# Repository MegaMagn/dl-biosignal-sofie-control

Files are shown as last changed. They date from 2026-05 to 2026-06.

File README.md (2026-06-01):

# Deep Learning-Based Biosignal Control of a Soft Hand Exoskeleton for Grasp Assistance

Soft, modular hand exoskeleton with integrated sensing and deep learning-based EEG/EMG control for grasp assistance.

## Overview

This repository contains the files used for the development of a soft hand exoskeleton and a deep learning-based biosignal classification framework for real-time grasp assistance.

The project is divided into two main parts:

* **Exoskeleton**
  Contains the mechanical design files, embedded firmware, electronics-related code, and supporting files required to fabricate, assemble, and control the soft hand exoskeleton.

* **Deep Learning-Based Classification**
  Contains the code used for EEG/EMG preprocessing, model training, validation, real-time classification, and biosignal-based control demonstrations.

Together, these components form a soft wearable exoskeleton system capable of assisting pinch grasping through tendon-driven actuation and user-intention decoding.

## Repository structure

```text
.
├── Deep Learning-Based Biosignal Control of a Soft Hand Exoskeleton for Grasp Assistance - report
├── Supplementary - Deep Learning-Based Biosignal Control of a Soft Hand Exoskeleton for Grasp Assistance
│   
├── Exoskeleton
│   ├── Code
│   ├── Enclosure
│   ├── Index and thumb version
│   ├── Index only version
│   └── Miscellaneous
│   
└── Deep Learning-Based Classification
    ├── Code
    │   ├── data_fusion
    │   ├── experiment
    │   ├── models
    │   └── utilities
    │
    └── MuJoCo
```

## Folders and files

### Exoskeleton

#### Code

Contains the embedded and computer-side code used to control, communicate with, and log data from the exoskeleton.

* **Arduino_ESP32 project files**
  Contains the Arduino `.ino`, `.cpp`, and `.h` files for controlling the exoskeleton and logging sensor data on the ESP32.

* **Arduino_ESP32_EMG_control project files**
  Contains the Arduino `.ino`, `.cpp`, and `.h` files for controlling the exoskeleton using commands from the classification network.

* **ESPLogger.py**
  Python script for communication and data logging between the computer and the exoskeleton.

* **requirements.txt**
  Required Python packages for the exoskeleton-side logging and communication scripts.

#### Enclosure

Contains the `.stl` files used for the electronics and actuator enclosure.

#### Index and thumb version

Contains the `.stl` files for constructing the main glove, the thumb module, and the index module. This folder also includes different PTFE tube clamps used to secure the tendon guide tubes to the glove.

#### Index only version

Contains the `.stl` files for constructing the main glove and index finger module. This version was used for early testing and characterization of the integrated sensors.

#### Miscellaneous

Contains miscellaneous files used for test setups, fixtures, and supporting experiments.

### Deep Learning-Based Classification

Contains the code used to develop and evaluate the biosignal classification framework.

This includes scripts for:

* EEG and EMG preprocessing
* Dataset preparation and segmentation
* Subject-dependent and subject-independent model training
* LSTM, CNN+LSTM, and CNN+LSTM+Attention models
* EEG/EMG decision-level fusion
* Hyperparameter optimization
* Real-time inference
* Digital twin visualization
* Biosignal-based exoskeleton control demonstrations

## Hardware needed

The following hardware was used for the exoskeleton system:

* ESP32 30-pin development board
* Pololu Micro Metal Gear Motor, 6 V, 250:1 gear ratio
* Pololu 5 V step-up/step-down buck converter
* SparkFun Micro Magnetometer - MMC5983MA, Qwiic
* 6 mm × 2 mm round neodymium magnet
* Adafruit PCA9546 4-channel STEMMA QT / Qwiic I2C multiplexer
* Pololu DRV8835 dual motor driver
* 7.4 V, 1000 mAh, 2S LiPo battery
* 1 kΩ resistors for the StretchSense voltage divider
* Flexible braided thin steel wire for tendon actuation
* PTFE tubing for tendon guidance
* Assorted resistors, capacitors, and an operational amplifier for current sensing, if desired

## Materials and printing

The exoskeleton is primarily printed in **varioShore TPU** from colorFabb using a Prusa MK3S and a Prusa XL 5T.

Recommended printing settings from colorFabb were used, with a nozzle temperature and layer height of:

```text
220 °C
0.2 mm
```

The StretchSense sensor is printed using **Conductive Filaflex TPU** from Recreus. The filament should be dried before printing and printed using the recommended settings from Recreus. In this project, StretchSense was printed on a Prusa MK3S using a nozzle temperature and layer height of:

```text
240 °C
0.1 mm
```

## Software environment

The Python code was developed using Python 3.11.

Create and activate a virtual environment:

```bash
py -3.11 -m venv .venv
source .venv/Scripts/activate
```

Install the required Python packages:

```bash
pip install -r requirements.txt
```

On Windows PowerShell, the virtual environment can also be activated using:

```powershell
.venv\Scripts\Activate.ps1
```

## Arduino / ESP32 setup

The exoskeleton firmware is intended to run on an ESP32 development board using the Arduino framework.

Before uploading the firmware, make sure that:

* The ESP32 board package is installed in the Arduino IDE.
* The correct ESP32 board and COM port are selected.
* Required libraries for the motor driver, I2C sensors, and communication are installed.
* The wiring matches the pin definitions used in the firmware configuration files.

## Notes

This repository contains research prototype files. The exoskeleton was developed for experimental validation and should be tested carefully before being used with human participants.

When working with the device:

* Check tendon routing before actuation.
* Verify motor direction and software limits.
* Ensure that the exoskeleton can release tension safely.
* Avoid excessive tendon tension.
* Disconnect power when modifying the electronics or mechanical structure.

## Project title

**Deep Learning-Based Biosignal Control of a Soft Hand Exoskeleton for Grasp Assistance**

## Authors

Magnus Malthe Sigsgaard Nielsen  
Nicklas Nikolaj Grønvall

University of Southern Denmark
SDU Biorobotics / SDU Soft Robotics

## License

No license has currently been selected for this repository. All rights reserved.

The contents of this repository are made available for reference and documentation purposes only. Non-commercial use, sharing, distribution, and reproduction in any medium or format are permitted, provided that appropriate credit is given to the original authors and source

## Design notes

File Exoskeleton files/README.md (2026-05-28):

# SoFiE: Soft Finger Exoskeleton for Intelligent Grasping
Soft, wearable, 3D printable, and modular exoskeleton with integrated tactile and proprioceptive sensing.

## Overview
Here, you will find all the necessary files to print and assemble your own soft exoskeleton and control it.

## Folders and files
- Code  
  - Arduino_ESP32 project files  
      Contains the Arduino .ino file and the .cpp and .h files for controlling and logging data on the ESP32.
  - Arduino_ESP32_EMG_control project files  
      Contains the Arduino .ino file and the .cpp and .h files for controlling the exoskeleton with the classification network.
  - ESPLogger.py  
      The logging and communication script meant to run on the computer in conjunction with the exoskeleton.
  - requirements.txt  
      required python packages
- Enclosure  
    Contains the .stl files used for the electronics enclosure.
- Index and thumb version  
    Contains the .stl files for constructing the main glove part, the thumb module and the index module, along with an assortment of PTFE tube clamps used to secure the PTFE tubes to the glove 
- Index only version  
    Contains the .stl files for constructing the main glove part and the index module.
- Miscellaneous  
    Contains some miscellaneous files for some of the test setups
   
## Hardware needed
* ESP32s 30 pin devboard
* Pololu Micro Metal Gear Motor (6V, 250:1)
* Pololu 5V Step up/Step down buck converter
* sparkFun Micro Magnetometer - MMC5983MA (Qwiic)
* 6 mm x 2 mm round Neudymium magnet
* Adafruit PCA9546 4-Channel STEMMA QT / Qwiic I2C Multiplexer
* Pololu DRV8835 Dual Motor driver
* 7.4 V, 1000 mAh, 2S LiPo battery
* 1 k Ohm resistors for StretchSense voltage divider
* flexible braided thin steel wire
* A lenght of PTFE tubing
* Assortment of resistors, capacitors and an opAmp for current sense if wanted.

## Materials and printing
The exoskeleton is primarily printed on a Prusa MK3s and a Prusa XL 5T in red varioShore TPU from Colorfabb. It is printed using their recommended settings, at a nozzle temperature of 220°C  
The StretchSense sensor is made of Conductive Filaflex TPU from Recreus, again dried and printed using their recommended settigns on a Prusa MK3s at a nozzle temeperature of 240°C

## Environment
Python version: 3.11  
Install:  
py -3.11 -m venv .venv  
source .venv/Scripts/activate  
pip install -r requirements.txt

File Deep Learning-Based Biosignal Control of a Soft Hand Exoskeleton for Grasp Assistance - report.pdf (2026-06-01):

# Deep Learning-Based Biosignal Control of a Soft Hand Exoskeleton for Grasp Assistance

Magnus Malthe Sigsgaard Nielsen1

## , Nicklas Nikolaj Grønvall¹

, Xiaofeng Xiong*¹
and Saravana

Prashanth Murali Babu*¹

1SDU Biorbotics, SDU Soft Robotics, University of Southern Denmark, Odense, 5230, Denmark

E-mail: xizi@mmmi.sdu.dk, E-mail: spmb@mmmi.sdu.dk.

*Supervisor.

Keywords: Brain-Computer Interface, Exoskeleton, Real-Time control, Soft Robotics, Deep Neural Network, Flexible Mechanism

### Exam number: Magnus Nielsen: 182180190 ; Nicklas Grønvall: 4110717

Exam project: Master thesis (Robot Systems) (Drones and Autonomous Systems)

## Date of Submission: June 1, 2026

## Word count: ~24400

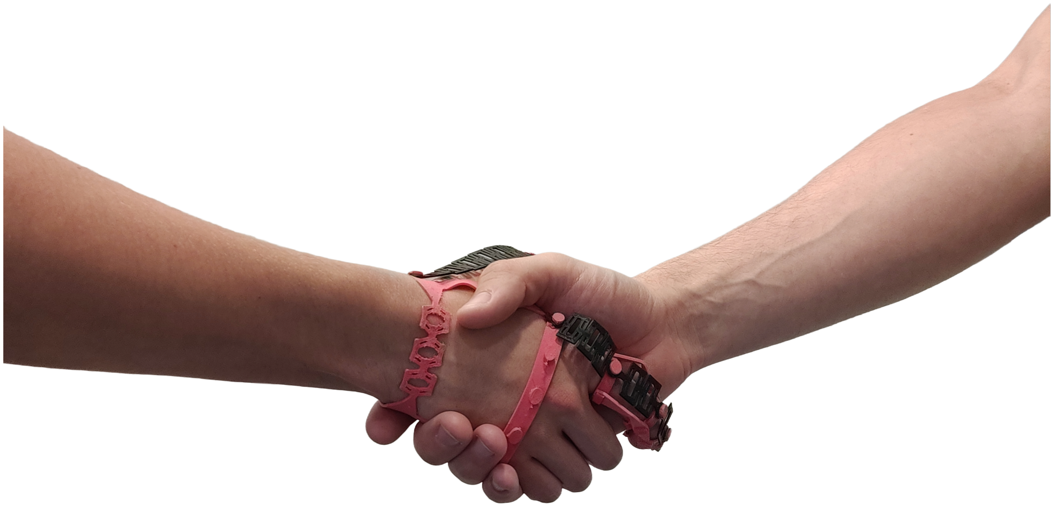
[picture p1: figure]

# Abstract

Hand function and independent dexterity are frequently compromised by age-related decline, trau-

matic injury, and prevalent inflammatory or neurological conditions such as rheumatoid arthritis and

carpal tunnel syndrome. This thesis presents the design, fabrication, and testing of SoFiE (Soft Finger

Exoskeleton for Intelligent Grasping), a lightweight, modular, 3D-printed soft wearable robotic plat-

form customized for pinch-grasp assistance. Fabricated using variable-shore TPU to optimize structural

compliance and user comfort. SoFiE utilizes a single-actuator, underactuated tendon mechanism with

a floating pulley to distribute force between the thumb and index finger. Two embedded sensing modal-

ities provide feedback: StretchSense, a conductive flexible spring providing passive extension forces

and proxy for position tracking, and MagSense, a fingertip magnet-magnetometer pair that measures

contact detection and material compliance. To enable intuitive control, an intention decoding control

pipeline was developed using sequential deep learning architectures, including LSTM, CNN+LSTM,

and CNN+LSTM with attention, evaluated across EEG and EMG signals. System evaluations across

17 participants proved that while decision-level multi-sensor fusion suffers from low EEG signal-to-

noise ratios, an EMG-driven CNN+LSTM network architecture effectively overcomes muscle crosstalk,

achieving an exceptional subject-independent classification accuracy ceiling of 99.4%. Real-time online

validation coupled with a digital twin yielded an optimal response latency of 0.45 ± 0.79 s. Finally,

functional human-in-the-loop grasping evaluations demonstrated that while a passive configuration

introduces minimal baseline resistance, active assistance dynamically attenuates user metabolic demand,

achieving a statistically profound 92.6% reduction in muscular effort during heavy, object-loaded lifting

tasks. These results demonstrate the potential of SoFiE for intuitive, low-effort pinch assistance using

real-time biosignal-driven control.

# Contents

1 Introduction | 3
2 Methods | 7
3 Experimental Methodology | 27
4 Results | 33
5 Discussion | 44
6 Conclusion | 51

# 1. Introduction

The human hand is among the most dexterous structures of the human body, allowing humans to

interact with and adapt to the surrounding environment. Through a combination of fine motor control,

powerful grasping, and rich tactile feedback, the hand can perform a wide range of daily tasks, from

delicate manipulation of small objects to stable handling of larger or heavier objects (Maw et al 2016).

In addition to being mechanically important for grasping and manipulation, the hand is central to tactile

perception and adaptive interaction with the environment (Fischer et al 2014). Despite this versatility,

hand function is vulnerable to impairment caused by neurological disorders, physical injury, repetitive

strain, inflammatory disease, and age-related decline (Gopal et al 2022).

Carpal tunnel syndrome | (CTS) is | a | common | hand impairment associated with repetitive | and

monotonous wrist activities, as well as rheumatoid inflammation. CTS can cause pain, numbness, and

tingling in the hand, especially in the thumb and index finger, and may reduce grip strength and hand

function (Genova et al 2020).

Rheumatoid arthritis (RA), the most common form of inflammatory arthritis, is characterized by

immune-mediated damage to joints, muscles, tendons, and bone structures. This leads to inflammation,

swelling, pain, and in severe cases permanent disability. RA commonly affects small joints, including

those in the hands and feet (Mohammed et al 2020).

CTS, RA, neurological disorders, physical injuries, and age-related weakness can all reduce hand

mobility, grip strength, and the ability to perform activities of daily living. These limitations are espe-

cially problematic when they affect the pinch grasp, since pinch motion is essential for fine and precise

manipulation. Modern grasp taxonomies identify thumb-finger and lateral pinch patterns as important

grasp types used in everyday manipulation tasks (Feix et al 2016; Napier 1956) and the coordination

between the thumb and index finger allows humans to pick up small objects, button clothes, hold a pen,

operate tools, and interact with electronic devices (Duruoz 2014; Kivell 2021).

For people with reduced hand function, loss of pinch strength or pinch coordination can therefore

reduce functional independence and quality of life (Hyun et al 2015).

To address hand impairments like RA, clinical care often combines exercise and rest with assistive

devices to preserve mobility and minimize joint stress Boer et al 2009. This motivates the development

of soft wearable hand exoskeletons capable of assisting grasping and reducing muscular effort. For

effective pinch assistance, such devices must provide sufficient force, coordinated thumb-index motion,

reliable sensing, and compliant, comfortable hand interaction. Assistive hand devices can be passive or

active (Birch et al 2008), depending on whether they support the hand mechanically or provide powered

assistance or resistance. One example of an active assistive device is the I-Phlex finger exoskeleton

(Figure 1A), which demonstrated how active mobilization can increase the range of motion of the

knuckles and thereby reduce joint stiffness (Peperoni et al 2024).

More generally, hand exoskeletons have evolved from rigid linkage-based systems toward softer and

more wearable architectures. Rigid exoskeletons can provide accurate motion guidance and high force

transmission, and they have shown strong potential for rehabilitation and force augmentation (Plessis

et al 2021; Sarac et al 2019). However, they often require careful joint alignment, include bulky

mechanical structures, and may restrict natural hand motion or reduce comfort during prolonged use.

Soft and compliant hand exoskeletons address several of these limitations by using flexible materials,

tendon-driven mechanisms, fabric structures, or fluidic actuators (Figure 1B) that better conform to the

hand and allow more natural movement (Chu and Patterson 2018; Polygerinos et al 2015). Rudd et al.

proposed a sub $200 3D-printed soft hand exoskeleton (Figure 1C) for use in hand therapy, providing

a simpler, cheaper, and more flexible alternative to many commercially available products (Rudd

et al 2019). A review by Heo et al. compares different types of hand exoskeleton technologies for

rehabilitation and assistance. Although more than a decade has passed since the publication of the

review, many of the principles and mechanisms are still used in current designs (Heo et al 2012). The

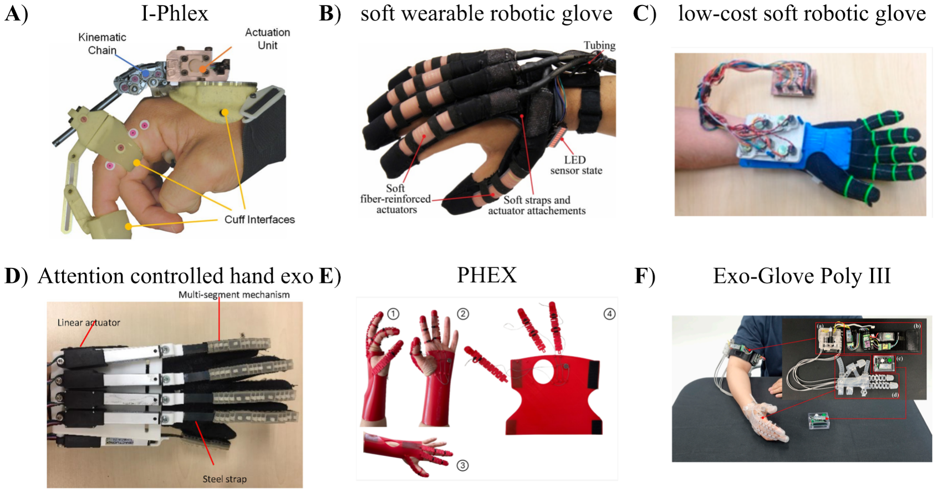
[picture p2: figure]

Figure 1. six examples of wearable robotic gloves. A I-Phlex designed by Peperoni et al. utilizing rigid links to transmit actuation force. B a soft wearable robotic glove designed by Polygerinos et al. using molded elastomeric chambers with fluid pressurization for actuation. C a low-cost soft robotic glove design by Rudd et al. utilizing 3D printing to minimize cost and tendons for actuation. D an attention controlled hybrid rigid-soft hand exoskeleton designed by Li et al. using EEG as a brain-controlled switch to actuate the exoskeleton. E PHEX, a pediatric hand exoskeleton for activities of daily living designed by D’Angelo et al. using a passive cable and spring setup for assisting finger motion. F Exo-Glove Poly III, a three finger exoskeleton designed by Kim et al. utilizing a soft elastomer glove, with a slack-based tendon actuation unit for grasp assistance.

review highlights that rigid systems are often mechanically complex or physically bulky, which can

complicate the development of multi-fingered variants. In contrast, soft and compliant mechanisms can

reduce mechanical complexity and improve wearability when combined with careful mechanical design.

Hybrid rigid–soft designs (Figure 1D) have also been explored to combine mechanical support

with improved wearability and user intention control (Li et al 2019). D’Angelo et al. proposed PHEX

(Figure 1E), a customized pediatric hand exoskeleton that uses a ribbon kirigami-inspired structure to

create a compliant dorsal mechanism. The design also incorporates multi-material cable guide rings

made from TPU and Nylon to improve wearer comfort while maintaining structural rigidity (D’Angleo

et al 2025). Kim et al. developed the Exo-Glove Poly III (Figure 1F), a three-finger soft hand exoskele-

ton based on an underactuated tendon-driven mechanism. Their design achieves multiple degrees of

freedom (DOF) using a single actuator and enables gesture control and manipulation with the thumb,

index finger, and middle finger through a slack-based sequential actuation strategy (KB Kim et al 2025).

Despite these advances, soft hand exoskeletons still face challenges in compact actuation, reliable

force transmission, sensing integration, portability, and intuitive control (Chu and Patterson 2018;

Plessis et al 2021). These challenges are especially important for pinch assistance, where the device

must remain lightweight and comfortable while coordinating thumb and index finger motion during

contact-rich object manipulation (Sarac et al 2019). Many soft systems rely on pneumatic or hydraulic

hardware, off-board actuation, or bulky control units, which can limit portability and everyday use.

Other systems improve portability but may still be difficult to customize for individual hand anatomy

or require complex fabrication and assembly.

In addition to actuation mechanisms, sensing is an important part of hand exoskeleton design.

Reliable information about finger motion, tendon loading, fingertip contact, grasp force, and object

compliance is essential for safe and adaptive assistance. Heo et al. discussed several sensing technolo-

gies that have been used, or could be used, in hand exoskeletons, including finger pad deformation

sensing for estimating gripping force. Nakatani et al. designed a compact sensor placed on top of

the fingernail, with T-shaped prongs extending to both sides of the finger pad. These prongs used

strain gauges to measure horizontal deformation of the fingertip, while avoiding obstruction of the

wearer’s natural tactile interaction with the object being touched (Nakatani et al 2011). More recently,

Pattabiraman et al. proposed a magnetic touch sensor based on cut-cell microstructures for sensing

gripping force and slip in robotic actuators (Pattabiraman et al 2025). While these sensing approaches

provide information about the interaction between the hand, exoskeleton, and object, assistive control

also requires information about the user’s hand movement.

To capture hand movement, researchers frequently turn to physiological biosignals. Among these,

electroencephalography (EEG) serves as a method for decoding neural commands directly from

the brain. The foundational principles of this technique date back to 1924, when Hans Berger first,

recorded the electrical activity of the brain and identified the alpha and beta rhythms as fundamental

patterns of brain activity (Tudor et al 2005). The field later developed into brain-computer interfaces

(BCIs), which establish a communication pathway between brain activity and external devices without

relying on peripheral nerves or muscles (Vidal 1973). BCIs have since been applied in areas such

as neurorehabilitation, prosthetic control, emotion recognition, and gaming. However, practical BCI

systems remain limited by challenges such as poor portability, low signal-to-noise ratio (SNR), limited

spatial resolution, artifacts, inter-session and inter-subject variability, and the trade-off between model

complexity and real-time performance (Sarhan et al 2023; Värbu et al 2022).

Additionally, electromyography (EMG) provides a complementary biosignal by measuring the elec-

trical activity generated during muscle contractions. Surface EMG is non-invasive and well suited for

motion-related decoding, especially when the goal is to identify active muscles, movement onset, or

performed movements. EMG-based pattern recognition has been used for real-time control of hand

exoskeletons and has demonstrated potential for supporting grip assistance in users with impaired hand

function (Lu et al 2017). However, standalone EMG also has limitations, since signal quality can be

affected by electrode placement, crosstalk, motion artifacts, electrical noise, muscle fatigue, paralyzed

limbs, neurodegenerative conditions, and inter-subject variability (Karthick and Ramakrishnan 2016;

Sarhan et al 2023). These limitations can degrade classification accuracy over time and make general-

izable control difficult, especially in real-time wearable applications.

Recent BCI research has therefore shown increasing interest in hybrid systems that combine multiple

physiological signals to improve robustness. Pfurtscheller et al. demonstrated a simultaneous hybrid

BCI architecture in which brain activity was processed together with another physiological signal.

Their hybrid model achieved an accuracy of 84.5 ± 10.2, compared to 69.4 ± 8.6 for the conventional

BCI model. Although the improvement in mean accuracy was not statistically significant, the number

of participants affected by BCI illiteracy was reduced from 11 to 1, suggesting that hybrid systems can

improve robustness across users (Pfurtscheller et al 2010). Combining EEG and EMG is particularly

relevant because the two modalities provide different but complementary information. EEG can capture

central cues related to motor intention and planning, while EMG reflects peripheral muscle activation

during movement execution. In this way, EEG–EMG fusion can potentially connect the user’s intended movement with the corresponding muscular response, thereby improving the reliability of intent detec-

tion compared to either modality alone (Sarhan et al 2023).

The temporal nature of EEG and EMG signals makes sequential modeling important for biosignal-

based control. These signals vary over time and contain information related to movement onset,

sustained activation, and relaxation. Therefore, models used for real-time biosignal classification must

be able to extract meaningful temporal features while remaining computationally efficient enough for

real-time deployment. Recurrent neural networks, such as long short-term memory (LSTM), have

shown strong potential for modeling sequential data and capturing long-term dependencies (Graves

2013; Hochreiter and Schmidhuber 1997). Transformer architectures later showed that self-attention

could replace recurrent processing to improve sequence modeling and reduce computational cost in

translation tasks (Vaswani et al 2017). For high-frequency data streams, WaveNet demonstrated that

dilated causal convolutions can expand the receptive field and process long temporal sequences effi-

ciently (Van Den Oord et al 2016). Within biorobotics, EMG-based gesture recognition has shown that

CNNs can effectively decode EMG signals, while recurrent layers remain useful for capturing more

complex temporal dynamics (Cornelis et al 2018). However, many deep learning models remain com-

putationally demanding for long sequences and high-dimensional representations, leading to inference

bottlenecks that can limit real-time robotic control. This creates a trade-off between model complexity,

classification performance, and inference latency, which remains one of the central challenges in

practical BCI and hybrid BCI systems (Sarhan et al 2023; Värbu et al 2022).

This thesis presents the development of SoFiE, a soft wearable hand exoskeleton for pinch-grasp

assistance, together with a biosignal-based control framework for decoding user movement. The system

is designed to assist flexion of the index finger and thumb while remaining lightweight, modular, and

suitable for untethered operation. SoFiE will be developed as the physical assistance platform, and

primarily fabricated using flexible 3D-printed components. It will be actuated using a tendon-driven

mechanism, providing the tension necessary for finger flexion, while sensing will be integrated directly

into the mechanical structure of the device with two novel sensors.

StretchSense, a compliant conductive spring element for proprioceptive sensing, and MagSense, a

finger tip mounted magnet–magnetometor sensor for contact and deformation related tactile feedback.

The biosignal-based control framework for decoding user movements will be developed with emphasis

on low-latency operation and subject-independent performance. Motion recognition will be evaluated

using sequential deep learning architectures, including LSTM and CNN+LSTM models, while atten-

tion is explored as an additional mechanism. The functional effect of the exoskeleton will be assessed

by comparing muscular effort across three conditions: no exoskeleton, passive exoskeleton, and active

assistance during isolated finger flexion and object grasping tasks. The real-time performance of the

deep learning-based framework will be assessed by classifying isolated finger flexion and two grasping

styles, visualizing the predicted movements with a digital twin, and evaluating both classification

accuracy and movement-to-visualization latency. To evaluate the framework’s capacity for fine-motor

control, the model will be specifically tested on its ability to differentiate between individual flexion

and extension motions for all five fingers. Classification performance will be quantified by recording

correct predictions, self-corrections, misclassifications and response time during the task.

We hypothesize that a EEG–EMG multimodal fusion framework will have improved motion classi-

fication accuracy when compared to a unimodal EEG or EMG framework. We further hypothesize

that adding convolutional feature extraction and attention to an LSTM improves the robustness and

ability to generalize compared with standalone LSTM. We hypothesize that an exoskeleton with a

modular tendon-driven architecture and integrated proprioceptive sensing and tactile feedback do not

significantly increase muscular effort when worn passively. Furthermore, the exoskeleton is designed

to preserve natural hand dexterity, ensuring that its physical structure does not impede finger mobility.

# 2. Methods

# 2.1. Design and Fabrication of SoFiE

The exoskeleton hardware platform developed in this work, hereafter referred to as SoFiE (Soft Finger

Exoskeleton for Intelligent Grasping), is a wearable assistive device designed to support grasping

through flexion of the index finger and thumb. According to a review by Hill et al. a problem that exists

with the development of exoskeletons today is that engineers and scientists do not have the end user

in mind during development (Hill et al 2017). During the development of our proposed design, we

have tried to have a potential end user in mind. The system is developed with emphasis on low profile,

compliance, portability, and user comfort. Rather than using rigid revolute joints that must be precisely

aligned with the biological finger joints, SoFiE relies on a compliant glove-like structure that conforms

to the user’s hand and follows the natural kinematics of the digits during motion. This approach reduces

the need for exact anatomical alignment and allows the device to remain lightweight and unobtrusive

during use.

SoFiE was first developed with only the index finger module. The index finger was chosen to

prove the concept as it was simpler to actuate than the thumb, but is still an essential part in completing

basic manipulation tasks. The index finger is also similar in shape and size to the three other fingers,

making it possible to create those modules in the future with only slight modifications to the design of

the original module. The index-only configuration will be presented first and used later for characteriza-

tion of the two novel sensors developed during this work. Even though the two configurations of SoFiE

share many similarities due to its modular design, the version with actively assisted index and thumb

(pinch configuration) will be presented later. The pinch configuration will be used in conjunction with

the deep learning-based control framework as a final configuration of SoFiE. With time, it could be

expanded to assist all five digits of the hand. A view of the design featuring the index and thumb assist-

ing version of SoFiE is shown on Figure 2, with a general overview of the entire system on Figure 2A.

The | exoskeleton | is | fabricated from | 3D-printed thermoplastic | polyurethane | (TPU). | A variable-

shore TPU (varioShore TPU, colorFabb) is used for the main glove structure, allowing the printed

parts to combine flexibility with sufficient local stiffness for tendon guidance and load transfer. The

varioShore TPU contains a foaming agent that, when activated, creates less dense parts that also have a

softer texture, making it more comfortable against the skin. The foaming property is also what makes

the filament able to change shore hardness during printing. It can vary from 92 Shore A to 55 Shore A

from a harder TPU to a soft TPU. The foaming is controlled using the temperature at which the TPU

is printed at, and for a compromise between toughness, a soft texture, and the increased flexibility that

comes with the foamed filament, the varioShore TPU parts of the exoskeleton was printed at 220 °C.

The glove has spring elements integrated into the wrist band to allow for further local stretching during

wrist motion, letting the glove keep it’s tight fit when the user moves their hand. The finger module

is constructed from open ring-like segments (phalanx rings) positioned along the phalanges and con-

nected dorsally by the stretch sensor, a compliant spring structure (see Figure 2E). On each side of the

finger, the phalanx rings are also connected using a small bar for stabilizing the rings and keep them

aligned on the finger, have the right spacing, and to reduce unwanted twisting of the module. Everything

is designed as individual modules that can be fitted together by snapfit for secure mounting and easy

assembly and disassembly. The glove with both thumb and index finger is shown on Figure 2C, with

the modular architecture shown in detail on Figure 2E. The modular architecture allows the device to

be adapted to different users and simplifies replacement or redesign of individual elements without

requiring the complete glove to be re-manufactured. The compliant material also accommodates minor

geometric differences between users and helps maintain comfort during repeated bending.

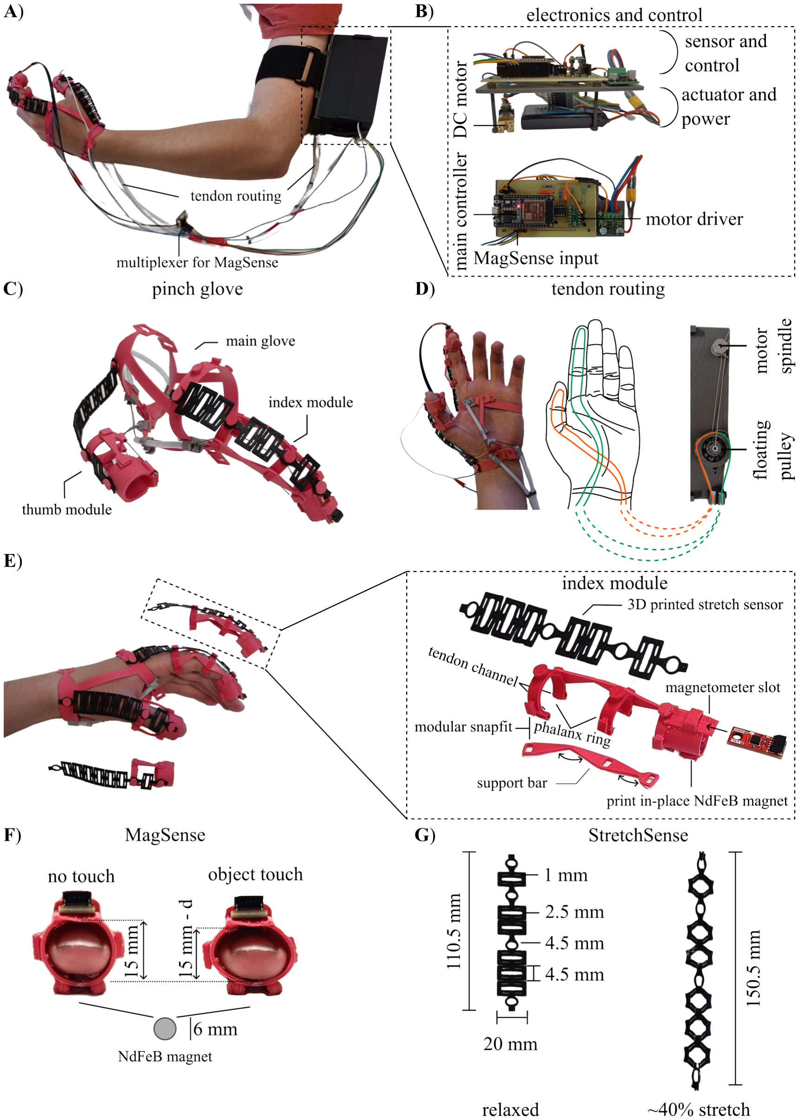
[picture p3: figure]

Figure 2. Overview of SoFiE. A shows the exoskeleton worn by a user. B an interior view of the enclosure housing the electronics for controlling the exoskeleton. C is the main glove with the index and thumb module attached. D is a diagram showing how the tendons are routed for pinch motion, utilizing the floating pulley as a passive differential. E is closer look at how the glove is worn with a disassembled view of the index module. F shows the MagSense sensor doing conceptual sensing, displacing the tissue whit the distance d. G is the StretchSense sensor in shown in a relaxed and a fully stretched state, increasing its total length by 40%.

To reduce the apparent weight on the hand, the actuator, battery, and control electronics are housed in

a separate enclosure, which is strapped to the upper arm. Placement of the electronics can be seen on

Figure 2A and a closer view of the electronics are found on Figure 2B. This arrangement moves the

heaviest components closer to the body and leaves only the glove, tendons, and sensing elements on

the distal limb. The resulting architecture preserves wrist mobility and reduces the amount of hardware

directly mounted on the hand, which is important for both comfort and practical use. The electronics

are configured in a stacked layout with two layers. On the top layer, a custom circuit-board is mounted.

To this, the ESP32 30pin development board acting as the main controller is mounted together with a

Pololu DRV8835 motordriver. Incoming sensorwires, and power is also distributed through this board.

A step-down/step-up buck converter is also integrated into the top layer, responsible for delivering

5 V to the system. At the bottom layer is the single Pololu micro metal gear motor with 250:1 gear

ratio that actuates the exoskeleton, and a 7.4 V 1000 mAh Lithium-Polymer (LiPo) battery responsible

for powering the system. The 7.4 V of the battery is too high for the ESP32 and the motor, and it is

therefore stepped down to 5 V using the aforementioned buck converter. The layered architecture is

illustrated on Figure 2B.

# Actuation Mechanism

Finger flexion in SoFiE is generated using a tendon-driven actuation mechanism powered by a single

250:1 micro metal gear motor located in the upper-arm enclosure. The motor rotates a small spindle that

winds or unwinds a thin steel tendon. The mechanism is shown on Figure 2D. Mechanically, the tendon

functions as a remote flexor element: when the spindle winds the tendon, the length of the tendon is

reduced, thereby creating a tensile force along the routed tendon path. Because the tendon is constrained

by polytetrafluoroethylene (PTFE) guide tubes along the arm and by tendon channels on the phalanx

rings, this tensile force is directed toward the distal part of the digit and produces a flexion moment

about the finger joints. SoFiE therefore does not actuate each joint separately using rigid links or aligned

revolute joints. Instead, the tendon routing, compliant exoskeleton structure, and natural kinematic con-

straints of the hand together determine the resulting grasping motion. Since tendons can only transmit

tensile forces, finger extension is not actively driven by the motor but is instead provided by the elas-

tic restoring forces of the finger and the compliant structure of the glove when tendon tension is released.

In the index-only configuration, the tendon is secured to the motor spindle and routed from the

upper-arm enclosure through a PTFE guide tube to the wrist. From here, it continues across the palm

and along one side of the index finger through the tendon channels integrated into the phalanx rings.

At the fingertip, the tendon loops around the distal fingertip structure in a dedicated channel before

returning down the opposite side of the finger. It then enters a second PTFE guide tube at the wrist and

returns toward the electronics enclosure, where it is fixed. The tendon routing follows the same path as

shown in green on Figure 2D, just attached to the spindle instead of wound around the floating pulley.

When the spindle winds the tendon, the loop is shortened and tension is applied along both sides of

the routed path. This pulls from the distal region of the finger and draws the fingertip toward the palm,

producing flexion in a way that is functionally similar to the natural flexor tendons of the hand. The

PTFE guide tubes reduce friction between the remotely placed actuator and the main glove, while also

constraining the tendon path so that the applied motor displacement is transferred primarily into finger

flexion rather than unwanted deformation of the soft structure.

# 2.2. StretchSense: Integrated Compliant Conductive Sensing

StretchSense is a compliant conductive spring integrated on the dorsal side of each digit. Its dimensions

and properties are shown on Figure 2G. Tjahyono et al. proposed a novel design for a flexible strain

sensor for their hand exoskeleton. They created this sensor by coating a natural rubber (NR) substrate

in polypyrrole (PPy), a conductive polymer, to create their NR/PPy structure or strain sensor, they use

for position feedback (Tjahyono et al 2013).

StretchSense takes some inspiration from their work, but differentiates itself by being dual purpose

as each StretchSense sensor serves two functions simultaneously. Mechanically, it provides passive

extension by storing elastic energy during flexion and assisting the digit in returning toward its neutral

position when tendon tension is released. Electrically, it acts as a strain-dependent resistor whose

resistance changes as the spring is stretched during finger flexion. The sensor is also fabricated from

conductive flexible TPU (Conductive Filaflex, Recreus) and is implemented as part of a voltage-divider

circuit. By measuring the corresponding voltage change during actuation, the microcontroller can obtain

a proxy measurement of digit deformation and thereby estimate the flexion state of the exoskeleton.

Integrating the sensing element into a component that is already mechanically useful avoids the need

for separate rigid encoders or external bend sensors on the fingers and supports the low-profile design

philosophy of SoFiE. The dual-purpose function of StretchSense is particularly advantageous for a

wearable hand exoskeleton. A single printed component simultaneously contributes to passive return

and proprioceptive sensing, reducing the number of discrete parts required on the hand. In the initial

hardware characterization (Section 4.1, StretchSense), different spring thicknesses were evaluated to

determine the relationship between restoring force, deformation, and resistance change. The same

sensing principle is retained in the final pinch configuration, with the additional thumb sensor enabling

deformation measurements from both actuated digits.

# 2.3. MagSense: Integrated Tactile Perception

To provide tactile information during grasping, SoFiE incorporates a compact fingertip sensor we have

chosen to call MagSense. A small neodymium magnet is embedded in the palmar fingertip structure,

while a magnetometer (Qwiic Micro MMC5983MA Magnetometer, SparkFun) is positioned dorsally

above the fingernail region. How it is integrated and conceptually works is shown in Figure 2F. The

magnetometer has a measuring range of ±8 G (Gauss). When the fingertip is in contact with an object, the

compliant TPU structure together with the underlying biological tissue deforms, reducing the distance

between the magnet and the magnetometer with a distance d. This change in distance produces a

measurable variation in magnetic flux density.

MagSense provides information that is complementary to both actuator position and StretchSense. While

motor encoder data describe motion at the actuator side and StretchSense reflects digit deformation of

the actuated digits, MagSense captures the local interaction between the exoskeleton and the grasped

object and can in that way be used as a safety measure as well. In preliminary experiments, the sensor

produced distinct responses when interacting with materials of different stiffness, demonstrating its

potential for contact detection and estimation of object compliance (Section 4.1, MagSense). Within

the complete SoFiE platform, MagSense therefore functions as a local tactile sensing modality that can

support future adaptive grasp control and contact-aware safety mechanisms.

# 2.4. Two Finger Exoskeleton

As mentioned before, the final version of SoFiE utilizes a pinch-style grasp, where both the index finger

and thumb are actuated. This is the version showcased in Figure 2 and it shares the same main glove

structure, electronics, and the index module is also carried over. Although it shares a lot of similarities

with the index finger version, it does add the thumb module and a floating pulley to the actuation

mechanism which changes the tendon routing as well. The thumb module consists of two phalanx rings

and a thumb specific StretchSense, but both are in a similar design to the index module.

On the present design of the index and thumb assisting SoFiE, MagSense is only implemented in the

index finger module. This was chosen in order to reduce the risk of magnetic cross-talk or disturbance

between adjacent sensors during grasping. Since the thumb and index finger approach one another

closely during pinch motions, placing a MagSense element on both digits would cause the field of

one magnet to influence the measurement of the other. By using MagSense only on the index finger,

the system keeps its tactile sensing capabilities while reducing the risk of sensor interference in the

two-digit architecture.

For the alteration of the actuation system, the motor still rotates the small spindle, but instead

of winding the tendon acting as the primary actuation at the fingertip, it now retracts a short primary

tendon that is connected to a free-floating pulley. The tendon routing and floating pulley is illustrated on

Figure 2D. A second, continuous tendon is routed around this pulley, with one branch passing through

the thumb module and the other branch passing through the index-finger module. Both branches are

routed through their respective PTFE guide tubes and tendon channels before returning to the pulley,

forming a closed secondary tendon loop. When the motor retracts the primary tendon, the floating

pulley pulls on the secondary tendon and increases tension in both branches. This allows the single

actuator to produce coordinated flexion of both the thumb and index finger. The floating pulley acts as

a passive differential between the two tendon branches. If both digits move freely, the tendon displace-

ment is shared between the thumb and index finger, producing a coordinated pinch motion. If one digit

is blocked by an object or in another way have a higher resistance, further displacement is distributed

to the digit with lower resistance. This allows the grasp to adapt passively to the object geometry rather

than forcing identical motion in both digits. The mechanism therefore supports underactuated pinch

grasping with a single motor, while keeping compliance and reducing the number of motors, drivers,

and control channels needed for the wearable system. However, the differential mechanism does not

allow the single motor to control each digit independently. Both tendon branches are tensioned during

actuation. The floating pulley only redistributes tendon displacement between the thumb and index

finger depending on the resistance encountered by each digit.

# 2.5. Electrophysiological Sensing Modalities

Biosignals provide a rich, continuous source of physiological sensing, reflecting both neural and muscu-

lar activity across the entire body. Nevertheless, acquiring high quality, discriminant biosignals remains

a challenge due to crosstalk interference, inter-subject variability, the difficulty of selecting optimal

channel locations for relevant content, and the complexities of interpreting neural perception during

stimulus activation. These obstacles arise partly from the complex anatomy of the human body and the

inherent limitations of current non-invasive acquisition technologies.

# Electroencephalography Dynamics

Electroencephalography (EEG) is a technique for non-invasively measure the electrical dynamics of

the brain. EEG signals primarily reflect the summation of postsynaptic potentials, meaning the total

exchange of electrochemical signaling across the synapses, across millions of pyramidal cells. However, postsynaptic potentials do not provide explanatory power of the EEG content such as spatial, spectral and

temporal features (Cohen 2017). On the contrary, specific oscillations and features have been of interest to

neuroscientists for understanding perceptual, cognitive, emotional, and motor processes. Throughout this

work, certain aspects have been inspected to explain the characteristics of EEG dynamics, one of which

is the frequency band-limited power: referring to how the signal rhythm behaves at different frequency

bands and are related to certain processes. These frequency bands are categorized as delta (0.5 – 4Hz),

theta (4 – 8Hz), alpha (8 – 13Hz), beta (13 – 30Hz), and gamma (> 30 Hz). Research demonstrates

that alpha and beta band suppression within the central sensorimotor region correlates with voluntary

movement execution. This concerns both motor execution (ME) that refers to physical movement,

and motor imagery which is the mental process of visualizing physical movement without physical

execution (Ding et al 2025). Another aspect of the EEG phenomena is EEG potentials. Specific event-

related potentials (ERP), are categorized by different frequency bands and cortical regions. These are

distinct, time-locked reactions formed by external or internal events (Sur and Sinha 2009). For example,

visual stimulation typically suppresses the occipital alpha rhythm, while performing ME reduces the

mu rhythm (8 – 13 Hz), which is localized over the central sensorimotor cortex. These characteristic

drops in localized frequency power are formally referred to as event-related desynchronization (ERD)

phenomena (Pfurtscheller 2001). The opposite is event-related synchronization (ERS) which refers to

a enhancement/rebound of the usual EEG oscillation. Such enhancements can be related to the mu

rhythms during visual stimulation or a beta rebound after ME (Pfurtscheller 2001).

# Electromyography Dynamics

Surface electromyography (sEMG) is a non-invasively technique in which electrodes are placed on the

skin to record electrical activity provided by motor units, allowing muscle fiber contractions. The motor

units are functional entities of the neuromuscular system. Each motor unit consists of a single motor

neuron and all innervated muscle fibers by its axonal branches (Garcia and Vieira 2011). Motor neurons

are a general term for neurons that are responsible for transmitting motor commands. The upper motor

neurons are a specific type that originate in the brain and transmit signals to the lower motor neurons

through the spinal cord. The lower motor neurons form the final neural pathway to the skeletal muscle

fibers, where their axons branch to innervate multiple fibers (Stifani 2014). Whenever a lower motor

neuron discharges, action potentials are generated at its neuromuscular junctions, that is the synapse

between the lower motor neurons and muscle fibers, and the summation of these action potentials which

propagate along the muscle fibers toward the tendon regions, are responsible for muscle contraction.

The measured EMG activation intensity depends on the amount of active motor units and the rate at

which the unit discharges, but it varies depending on the muscle group, target force and the contraction

type (Garcia and Vieira 2011).

# 2.6. Multimodal BCI Methodology

This section presents the EEG – EMG multimodal classification pipeline used to decode hand motor

intentions from synchronized neural and muscular activity. The framework combines modality-specific

preprocessing with three sequential deep learning architectures of increasing complexity: a baseline

long short-term memory (LSTM) network, a hierarchical convolutional extension (CNN+LSTM), and

an attention-based extension (CNN+LSTM+Attention). Both unimodal classification and decision-

level fusion are evaluated to examine the contribution of each modality and the potential benefit of

multimodal integration. The section covers the complete pipeline shown in Figure 3, including sensor

placement, preprocessing, synchronization, signal characteristics, model architectures, hyperparameter

optimization, and training strategy.

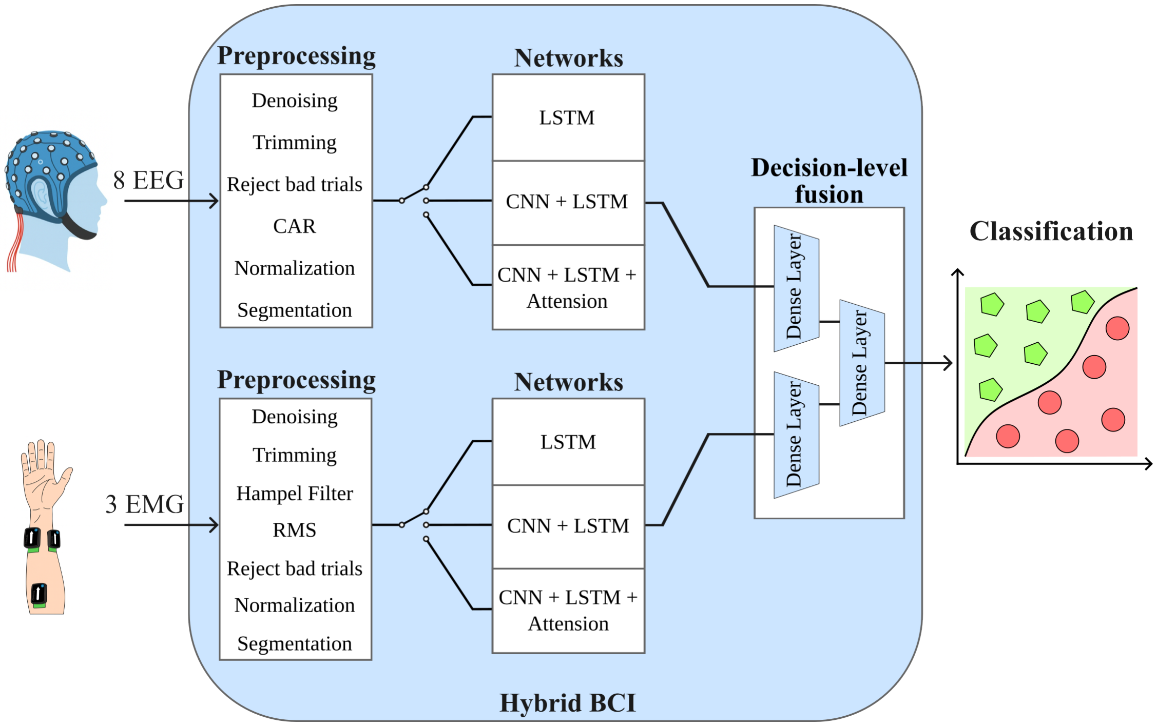
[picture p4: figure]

Figure 3. The Hybrid-BCI classification pipeline, in its wholeness will present a single multimodal. Each modality are processed separately and forwarded to one of the three networks. The networks extract distinct features and forwarded to a dense layer to archive logits. These logits are provided for the decision-level fusion that evaluates the final classification.

# EEG Channel Selection and Spectral Analysis

A clear trend appears in state-of-the-art research for EEG channel selection and band frequency uti-

lization, showcasing that the sensorimotor cortex among mu/beta bands are preferable for motor and

imagery execution. The remaining section highlights which channels and frequency bands gives the

strongest class separation, and for further details see the Supplementary Section S1. Five regions were

defined: prefrontal (Fp1, Fp2), frontal (F7, F3, Fz, F4, F8), central (C3, Cz, C4), temporal (T3, T5,

T6, T4), and partial (P3, P4), among five frequency bands delta (0.5 – 4 Hz), theta (4 – 8 Hz), alpha

(8 – 13 Hz), beta (13 – 30 Hz), gamma (30 – 60 Hz). To capture the full frequency range while sup-

pressing noise, a bandpass filter (Butterworth, 4th order, 0.5 – 60 Hz) and infinite impulse response

filter (Notch, 2nd order, 50 Hz) was applied. The dataset was segmented into equal sized trials, and

the resulting periods were concatenated regardless of the specific finger involved. The relative power

was computed per class (distinct, predefined label that the model is trained to assign to input data) for

each specific region, frequency band and participant. The results shows that relative power distribution

varies across participants, on average the highest power belong to delta band at the prefrontal region,

alpha band at the parietal region, and beta band at the central region. However, a repeated-measures

ANOVA revealed a significant effect (F(74, 1184) = 20.26, p ≪ 0.05), indicating differences across

classes, region, and frequency band combinations. A Cohen’s d analysis unfold delta, alpha, and beta in

frontal and central region to be the strongest contribution of class separation (Cohen’s d ∈ [0.36, 0.51]).

With that in mind, those eight channels at the unfolded frequency bands provides a strong baseline for

extracting meaningful, class separation content and are used in this work.

# EMG Sensor Placement Strategy

In order to distinguish between all fingers during flexor motions, three EMG sensors were placed at

the anterior forearm at the participant dominant hand. Figure 4B illustrates the EMG sensor locations

on the forearm, denoted as channel 1 though 3. Channel 1 is placed at the middle of the wrist flexor

group at the superficial view, primarily consists of the flexor carpi radialis, palmaris longus, and flexor

carpi ulnaris, each of these muscles contribute to flexion of the wrist (Okwumabua et al 2025). Though

experimental examination, this placement showed the highest activation during ring and middle finger

flexor motions. Channel 2 is placed to acquire the intermediate group activation, mainly the flexior

digitorum superficials. This muscle allows for flexion of the wrist, the knuckle joints, and the middle

joint of our four fingers, excluding the thumb (Okwumabua et al 2025). This placement have shown

superior activation during index and pinky activation. Lastly, channel 3 is placed to acquire activation

from the deep view flexor pollicis longus, which highlights similar functionality as the flexior digitorum

superficials, but innervate for the thumb instead (Okwumabua et al 2025).

# EEG Preprocessing

The first preprocessing step is denoising the signal to suppress drift and prioritize frequency bands

with discriminative information. A bandpass filter (Butterworth, 4th order, 0.5 – 30 Hz) and infinite

impulse response filter (Notch, 2nd order, 50 Hz) was implemented to extract those frequencies related

to ME and suppress power-line interference. The second step is trimming. The initialization of data

streaming for both the Trigno and OpenBCI hardware requires a startup period for the signal to stabilize.

Conversely, terminating the data stream can lead to dropped data packets. To counter these issues, a

three-second baseline recording, was included at the beginning and end of the experiment. This buffer

was subsequently removed from the dataset during preprocessing, preventing unstable signals, the loss

of informative data packets, and edge transient distortions from filtering. After trimming the data, it

is necessary to inspect if the data contain artifacts and remove them. Because normalizing immense

artifact spikes, will shrink the relevant signals and lower the signal-to-noise ratio (SNR), resulting in

poor data quality. The rejection routine is described later in the section (Synchronization and Rejection

Techniques). The Common Average Reference (CAR) computes the average potential across all of the

channels and subtracts it from each individual channel. Its a valuable technique for improving SNR and

removes common-mode noise. CAR is stated to outperform other standard types of referencing, leaving

more discernible signals (Ludwig et al 2009). The mathematical expression is stated in Table 1.

Finally, the EEG is normalized into a common scale using Z-score, showcasing how data samples falls

relative to the mean. The normalized data is then segmented into the fixed trials, which holds the rest,

onset, and offset periods.

# EMG Preprocessing

In order to suppress high frequency interferences and low frequency motion artifacts. The frequency

range varies across state-of-the-art studies. Based on the Trigno user guide and relative literature (Delsys,

Inc. 2021; Lee et al 2022; Phinyomark et al 2010), a bandpass filter (Butterworth, 4th order, 20 – 450 Hz)

and infinite impulse response filter (Notch, 2nd order, 50 Hz) was implemented for suppressing high

and low frequency components and power-line interference. The filtered EMG data is trimmed exactly

as EEG data when extracting the periods from the experiments. Looking back at our reasoning for the

sensor placement strategy, a common trait occurs for the individual muscle groups, as they are closely

interconnected. There exists a high possibility that a specific EMG channel captures neighboring muscles

activity, because of the difficulty of accurately isolating the targeted muscle, which is refereed to as

crosstalk (Bhowmik et al 2017). For example, a thumb contracting can be visible on channel 1, because

the pollicis longus (channel 3) closely bypasses the wrist flexor group. Additionally, unintentional muscle twitches, which are very common for people suffering from tremors, can cause immense impulsive spikes

in EMG measurements. These outliers can influence the statistical parameters of EMG recordings, thus

badly influence the classification model finalization.

The outliers have been analyses with an power spectral density estimate, highlighting these artifacts

belong to high frequency components of approximately 180−220 Hz and exists within the defined EMG

range of 20 − 450 Hz. To address this issue, a statistical filtering method, the Hampel filter (Bhowmik

et al 2017) is implemented to repair the signal. The Hampel filter implementation is stated in Table 1.

A set of local median windows are extracted from the continuous data-stream using a median filter, half

the window size is defined by k = 100. The Median Absolute Deviation (MAD) reflects the median of

absolute differences between each data sample and the corresponding median window, and is applied

with a normal scaling factor (1.4826) keeping MAD to a standard deviation scale. If the absolute

differences between the signal sample and corresponding typical value (|xi − mi

|) exceeds the MAD

criterion, that sample is replaced by its local median. The threshold factor (λ = 2) is empirically selected

to suppress muscle artifacts while preserving clean signals components.

The repaired signal from Hampel filtering will be transformed from a chaotic signal into a smooth,

easy-to-read waveform envelope, which quantifies the intensity and force of muscle activity. This is

acquired by using Root Mean Square (RMS), the difference between the Hampel filtered signal and

RMS envelope can be seen at Figure 4C. Achieving this goes as follows: a 1D moving average filter was

adopted to extract segments of the signal. The window size hold 500 ms of the signal and increments

by 50 ms (90% overlap), the RMS are computed for every window using the formula in Table 1. Lastly,

the RMS envelopes are normalized using Z-score and segmented into equally sized trials, same as with

the EEG preprocessing.

# Synchronization and Rejection Techniques

Marker alignment is an important tasks, it ensures that each trial begins at t = 0 with a rest period and

at exactly t = 3 the onset period begins, thereby preventing data drift between trials.

Data acquisition for each modality is implemented within a multi-process framework, enabling parallel

execution. Upon initialization, each modality process sends an acknowledgment signal to the main

process once it is fully ready. A blocking event object ensures that all modalities are synchronized and

prepared before acquisition begins. During this waiting phase, the modality buffers are continuously

flushed to remove unused samples and prevent stale data from affecting synchronization. Once the main

process receives acknowledgments from all modality processes, the experimental protocol starts, and

each process continuously acquires data without additional delay. Since trials are aligned, it is possible

to interpret trials across EEG and EMG data streams as the same modality, since they explain the same

event. In cases where human error or hardware malfunction occur during the experiment, they need

to be addressed and removed. For example, if the participants performs an unintentional motion, like

performing onset motion during the rest period, which can be observed in EMG recordings. Additionally,

swallowing, jaw clenching, coughing, and head movement causes abnormal EEG signal behavior. To

account for both artifacts and unintentional motions, two methods are suggested: auto-reject and manual-

reject. For manual-reject scenarios where the participant performs the wrong motion, will be noted

during the experiments and manually marked as a bad trial, thus removed during the artifact rejecting

preprocessing step. Auto-reject requires more finesse. A channel-wise rejection threshold are computed

across all trials within the same experiment. If a trial peak-to-peak value exceeds this threshold, the trial

is considered bad resulting in removing this trial from all modalities. Those channels not included in

the classification pipeline, does not affect the decision if the trial is bad. The mathematical expressions

are stated in Table 1 (Jas et al 2017).

Table 1. Mathematical formulation of the preprocessing pipeline, including signal processing and artifact rejection methods.

Feature | Formula | Dim.
Z-score normalization | zi =

xi − μ

σ

R

T×Cℎ

Root Mean Square (RMS) | RMS =

## vut

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
T×Cℎ

Common Mode Average (CAR) | C AR = xc −

1

N

∑︁

N

i=1

x

2
i | R

T×Cℎ

# Hampel Filter

Median window | mi = median(xi−k, . . . , xi
, . . . , xi+k) | R

T×Cℎ

Median Absolute Deviation (MAD) | M ADi = 1.4826·median(|x j−mi
|), | j ∈ [i−k, i+k] | R T×Cℎ
Outlier criterion | xi =

(
mi

, if |xi − mi

## | > λ · M ADi

xi

, otherwise

R

T×Cℎ

# Autoreject

Peak-to-Peak Amplitude | PT P = max(X) − min(X) | R

E×Cℎ

Channel Median | m˜ = median(PT P) | R

Cℎ

Channel MAD | M AD = median(|PT P − m˜ |) | R Cℎ
Rejection Threshold | tr = m˜ + τ · M AD | R

Cℎ

Epoch Rejection Rule | Epoch e is bad if ∃c | : | PT P > tr

Notation: xi = signal sample, xc = signal for channel c, N = number of samples in window,

k = half-window size, λ = threshold factor, τ = tolerance threshold, X = signal sequence for

one trial, E = number of epochs, T = number of samples, Cℎ = number of channels.

# Preprocessed Signal Characteristics

Figure 4 provides an overview of the biosignal responses to flexion contractions of the index finger

(Figure 4C, D, E, left column) and the thumb (right column), averaged across 90 trials. Figure 4B

illustrates the placement of three Delsys Trigno EMG sensors on the forearm muscles, which were

empirically localized to capture individual finger activations. The rationale for this configuration is

detailed in Section 2.6 (EMG Sensor Placement Strategy). Figure 4C displays the muscular activation at

channel 2 during index flexion (left) and at channel 3 during thumb flexion (right), showing both the raw

EMG sequence and its preprocessed RMS envelope for one trial. Each trial consists of three periods:

resting, onset, and offset. During the resting period, the participant’s hand is relaxed. The onset period

denotes the initiation of voluntary movement, represented by the hand silhouette. After approximately

0.7–0.9s, the amplitude increases due to muscle contraction, peaking when the finger is fully bent.

The offset period marks the transition back to the resting state, where the envelope returns to

the baseline noise floor. Figure 4A outlines the envelope distribution across all 90 trials for each channel

and movement. Generally, the median values reside within the baseline noise floor because the trials

remain in a resting state for the majority of the duration. However, the highest concentration of data

(the upper quartile and whiskers) shifts to channel 2 during index finger motion and channel 3 during

thumb motion. This distinct distribution indicates that these channels provide independent features for

classifying or explaining the two finger movements.

Figure 4D visualizes the preprocessed, averaged EEG recordings during the trial periods. The

signals are captured over the sensorimotor cortex within the left hemisphere (C3), as illustrated by

the inset. By analyzing the time-domain signal behavior, distinct EEG phenomena, that align with

supporting literature, are observable. Although, a perfect one-to-one comparison between EEG patterns

remains challenging due to intra- and inter-subject variability, differences in hardware equipment, envi-

ronmental influence, and variations in preprocessing techniques, all of which constrain signal quality.

Among these, state-of-the-art literature indicates that approximately 15 – 30 % of users are unable to

produce clear, easily detectable sensorimotor rhythms, such as mu and beta ERD. These deficiencies

underscores the complexity of EEG interpretation and challenge of identifying domain-invariant EEG

feature representations (DH Kim et al 2023). To overcome these signal-to-noise ratio challenges and

reveal underlying cortical potentials, averaging multiple trials is a necessary approach to mitigate back-

ground noise while retaining phase- and time-locked neurological responses (Borràs et al 2022). Prior

to physical movement onset (Figure 4D, 0 – 3 s), the cortex remains in a steady baseline oscillation state.

Following the initiation of finger flexion at 3.0s, an increase of electrical response is observed

(S1). This transient peak represents the primary motor potential (MP), which is a trigger response

generated by the pyramidal neurons activations within the contralateral sensorimotor cortex (C3)

during the transition to an activation state (Cui and Deecke 1999). Following this initial ME, the signal

enters a transition phase (S2) between 3.0 – 4.0 s. Here the waveform dynamics reflect a suppression

of signal amplitude, driven by the occurrence of ERD in the sensorimotor mu frequency bands, due

to the execution of motion. Immediately after (S2) a signal rebound, causing an increase in waveform

magnitude, can be observed in (S3). This behavior is related to the motor event stimuli caused by

reaching the full flexion position (Barry et al 2014; Pfurtscheller 2001) and settles to the baseline prior

to the offset period. The offset period shows similar behavior as the onset period.

Figure 4E displays the topographical EEG potential mapping across the entire scalp grid. Dur-

ing the baseline resting state (0.0 – 3.0 s), the overall cortical topography remains neutral, with a minor

positive polarization localized to the frontal and prefrontal regions for both the index finger and thumb

tasks. Around the moment of ME, the negative potential emerges, localized specifically over the left

sensorimotor cortex (C3), suggesting that contralateral movement activates the opposite hemisphere

of the brain. (Cui and Deecke 1999). Notably, the thumb activation maps display generally lower

absolute potential values compared to the index finger, suggesting variations of cortical intensity during

thumb flexions. Finally, during the movement offset period, a broader spatial distribution are affected,

engaging electrodes C3, C4, and Cz during the extension motion of the finger.

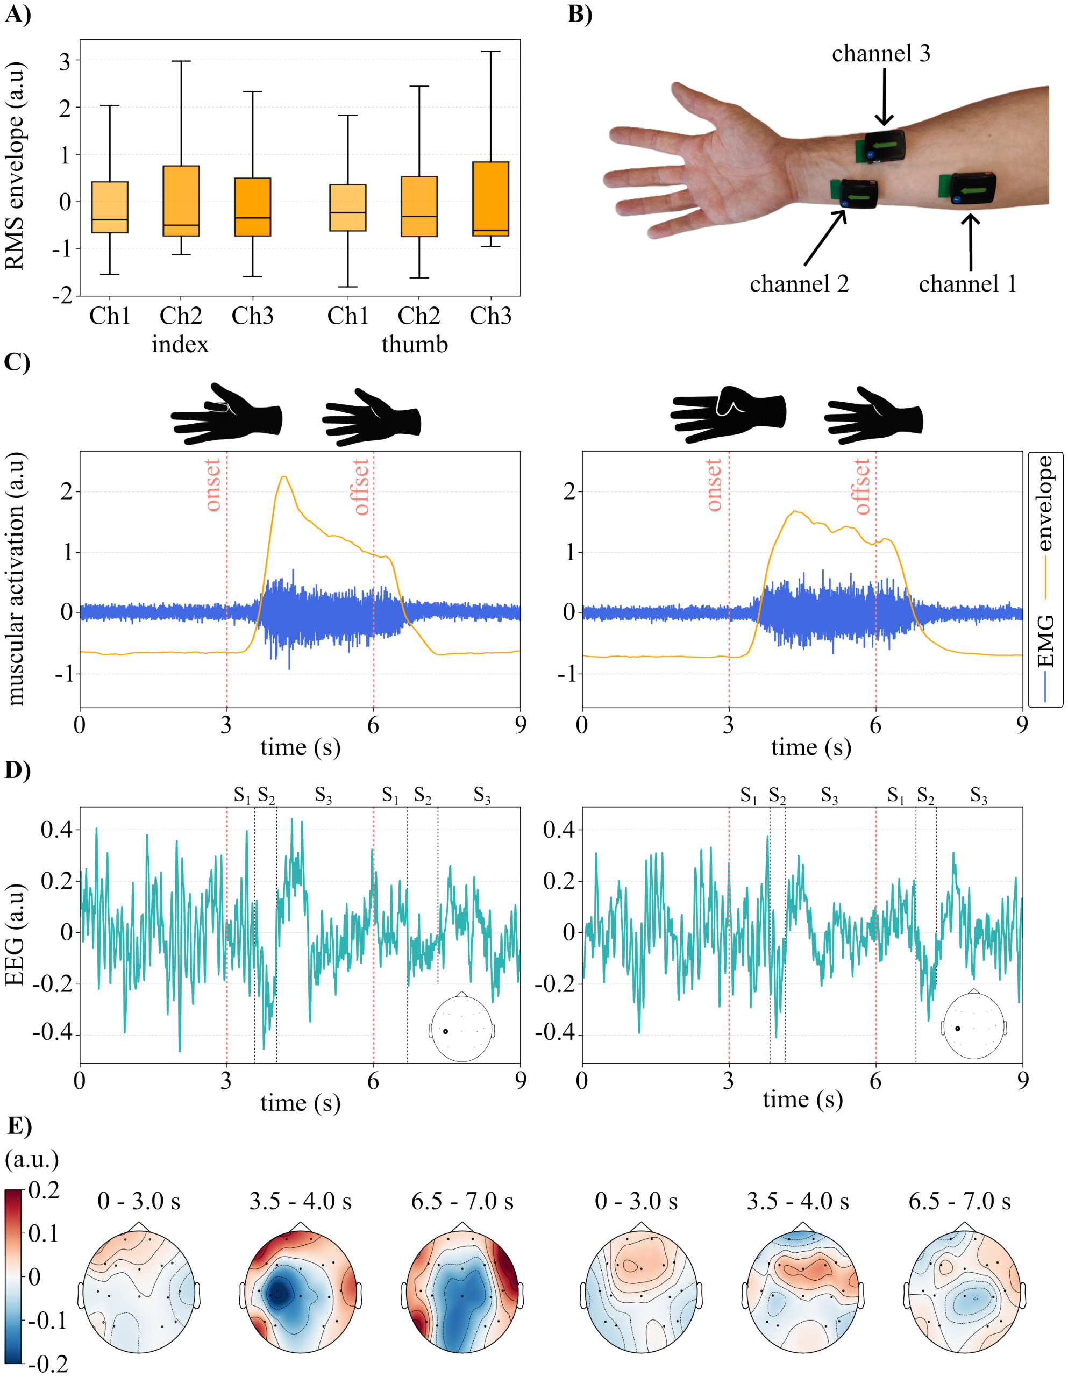
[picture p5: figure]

Figure 4. A displays the envelope distribution of individual fingers at each channel. B shows the EMG channel locations. Channel 1 is placed on the wrist flexor group, channel 2 at the flexor digitorum superficialis, and channel 3 at the flexor pollicis longus. The remaining figures C, D, E displays the muscular and neural response for index finger flexion (left column) and thumb flexion (right column), illustrated by the silhouette hand. C shows the average raw and processed EMG (envelope). D is the processed EEG sequence at C3, illustrated by the inset. E is its corresponding topographical mapping across all channels within the time-periods.

# Classification Architecture

This section presents the classification networks used to decode ME from the EEG and EMG modalities.

To investigate how the contribution of each modality can provide useful information, a set of networks

are proposed to extract features from the signals. However, effectively exploiting information remains

challenging particularly in subject-independent classification scenarios where inter-subject variability is

high. This work proposes a set of networks with increasing complexity to exploit both temporal and spa-

tial features among long-term dependencies. These networks are LSTM, CNN+LSTM, and CNN+LSTM

with attention mechanism, throughout this work the corresponding networks will be referred to as N1,

N2, and N3, respectively. Each network’s effectiveness will be evaluated across three modalities: EEG-

only, EMG-only, and the decision-level fusion using both modalities. The documentation and approach

are based on offline operation.

# Long Short-Term Memory

The long short term memory network (LSTM) is a special kind of recurrent neural network capable

of learning long term dependencies from sequential data. In other words, LSTM computes a feature

presentations influenced by past events.

How does it work: the LSTM architecture is shown in Figure 5, if it is only LSTM-based (not

influenced by other networks) the input sequences are switched to biosignals from either EEG or

EMG. The input is otherwise features from a CNN. The gray enclosure box, illustrates the unrolled

LSTM, which processes the first data sample x1 to the last data sample xT. For each data sample xt a

corresponding hidden state ℎt and memory cell Ct are forwarded to the next data sequence xt+1. The ℎt

captures short-term dependencies at current time, where Ct stores long-term dependencies and context

given the conveyor belt effect of the unrolled LSTM. Both ℎ0 and C0 are initialized to zero.

Additional configurations involve increasing the depth of the LSTM layers and employing a bidirec-

tional LSTM to capture both past and future context within the input sequence. The red enclosure box,

highlights one LSTM cell that incorporates a sigmoid function σ and tanh function.

The forget gate sum up the input sample xt and hidden state ℎt−1 after multiplying the them with the

corresponding weights and passing them through the sigmoid function. The σ decides which informa-

tion to accumulate, where values of σ close to zero removes information and close to one retains it.

The input gate adds useful information to the memory cell. The tanh function creates a potential

long-term memory, where values ranges between −1 and 1 for all possible values.

Similarly to the forget gate the sigmoid function regulates a percentage of the potential long-term mem-

ory for the LSTM to remember. The updated long-term memory Ct+1 is forwarded into the next LSTM

cell and passed through a tanh function to create a potential short-term memory and the percentage is

retained by the sigmoid function, producing the hidden state ℎt for the next LSTM cell and potentially

another depth layer if enabled. The final output can either be the last hidden state ℎ

1
T

or ℎ

l
T

, where l is

the last layer depth, with the dimensionality of (B, U), where B is the batch size and U is the number of

hidden units. The last hidden state serves as a condensed summary of the entire input sequence for the

dense layer. The alternative is forwarding the hidden state for each input sequence (ℎ

l
0

, ℎ

l
1

, . . . , ℎ

l
T

) to

the attention mechanism, with the dimensionality of (B, T, U).

# Convolutional Neural Network

The one-dimensional convolutional neural network (1D CNN) is a deep learning architecture used

to process one-dimensional sequence data by sliding filters across the time-domain. The 1D CNN is

capable of extracting a spatial-temporal feature map from the signal.

How does it work: the CNN architecture is shown in Figure 5, where a fixed size kernel (k)

slides across the time-domain until the full sequence (T) is reached, where a full sequence descries one

trial period. The kernel spans across all channels and the CNN computes a weighted sum over both the

time-domain and all the channels at once, resulting in spatial relationships across channels. Besides the

kernel size which determines the receptive field of the spatial feature map, the CNN expand its capacity

by filters (F) to identify different, unique feature in the data. An analogy could be that the kernel size

(k) is the size of the looking glass, deciding how much of the input we see at once. The filters (F) are

different learned lenses placed over that looking glass, each highlighting a different type of pattern. To

ensure stability and balance, BatchNorm is performed to normalize across batches and forwarded into

a activation function for adding non-linearity. The MaxPool applies a 1D maximum pooling operation

over the sequence with a kernel size of two. This effectively downsamples the sequence dimensions by

keeping the strongest activation, leading to the dimensionality of (B, T/2, F). Lastly, dropout is applied

as a regularization technique to prevent overfitting, by setting elements to zero with a probability value.

# Attention

There exists many versions of attention mechanisms, but in general they try to solve the long sequence

problem by selectively concentrate on specific information, while ignoring irrelevant distractions. An

effective and simple version was introduced in 2014, commonly known as Bahdanau attention (additive

attention), utilizing encoder-decoder framework to improve sequence-to-sequence networks. Even here

different variations of additive attention is introduced, but the core concept remain the same. Our work

takes inspiration from a general attention pooling mechanism, which does not require a decoder (Santos

et al 2016). The encoder, network flow, and components of the attention mechanism is illustrated in

Figure 5.

How does it work: the input sequence is encoded by the LSTM, providing the sequence of hid-

den states, H. If bidirectional is enabled, twice as many hidden states are available, where forward
−→ℎ t | and backward ←−ℎ t | are concatenated for the attention block. Looking at the red enclosed box

and corresponding equations in Table 2, the query (Q) represents what information we are looking

for, which holds the condensed summary of the sequence. The key (K) represents the identifier of

information, where value (V) contains the actual information at each sequence input. A relationship

is established between Q and the information for every step Kt

, which can be interpreted as: given

the attention understanding from the whole sequence, which time steps are important. The alignment

scores (et) intermediate the relationship strength, by taking the tanh function for a linear transformation

of zt

, where Wa | and ba | are the linear transformation weight and biases, respectively. Afterwards a

dot product is computed by the learnable weight vector (v

⊤
| | a ), by converting it into a single score for

every step. The softmax normalizes the alignment scores producing attention weights (αt), acting

like probabilities indicating importance. Finally, a context vector (c) is computed as a weighted sum

between attention weights and the encoder hidden states. Allowing the network to concentrate on the

most relevant temporal features within the sequence.

Table 2. Equations for the additive attention mechanism.

Step | Formula
Input sequence | K = V = H = [ℎ1, ℎ2, . . . , ℎT]
| Kt = Vt = ℎt , for t = 1, . . . , T
Query expansion | Q = ℎT
Concatenation | zt = [Q; Kt]
Alignment scores | et = v

⊤

a

- tanh(Wa · zt + ba)
Attention weights | αt =

exp(et )

ÍT
k=1

exp(ek )

Context vector (weighted sum) | ct =

ÍT
t=1

αtVt

# Notation: ℎt

is the hidden state at time step t, T is the sequence length, va, Wa, and ba are

learnable attention parameters, αt | is the normalized attention weight, and c is the context

vector.

The dense layer advance from features to classifications. See the last block element in Figure 5. The

input features are either the last hidden state from LSTM or the context from attention. Each dense

layers consists of two linear layers, an activation function, and a dropout layer. The primary objective

of this configuration is to reduce feature dimensionality prior to classification. The output z consists of

logits, which are unnormalized and unbounded scores. The class with the highest logit value represents

the model’s most confident classification for the input biosignal. When using both modalities, the

original architecture generates zi and a mirrored version generates zj where they are merged afterwards

into the final layer. This convention of consolidating multi-modal logits and mapping them into a

new dimensional space, is called decision-level fusion. It allows individual modalities to interpret the

biosignal and predict the corresponding task, whereas the decision-level fusion concludes the final

outcome based on the classification of both modalities (Leeb et al 2011). For example, the network

decodes with high confidence that the user executed a prehensile motion given the EEG response, how-

ever the mirrored network of EMG decodes correctly which muscle activations are involved although it

is confused whether the motion is grasping around an object or releasing the object.

The final classification outcome looks at the full picture, weighing the confidences and conclude the

task and muscle group involved. Another example, involves decoding of muscle artifacts, like muscle

flicks, which might bypass the preprocessing routine causing the EMG model to have a low confidence

classification of voluntary contraction, however if the EEG model counteract it by saying that it is in

idle state with a high confidence, the decision-level fusion leans toward ignoring the activity from the

muscle flick. Note, that the concatenation of zi and zj are normalized using z-score to ensure the logits

can be combined fairly, since individually, the confidence scale and magnitudes can appear differently.

Otherwise, one model with large-scale logits can dominate a more accurate model, which produces

smaller logit values.

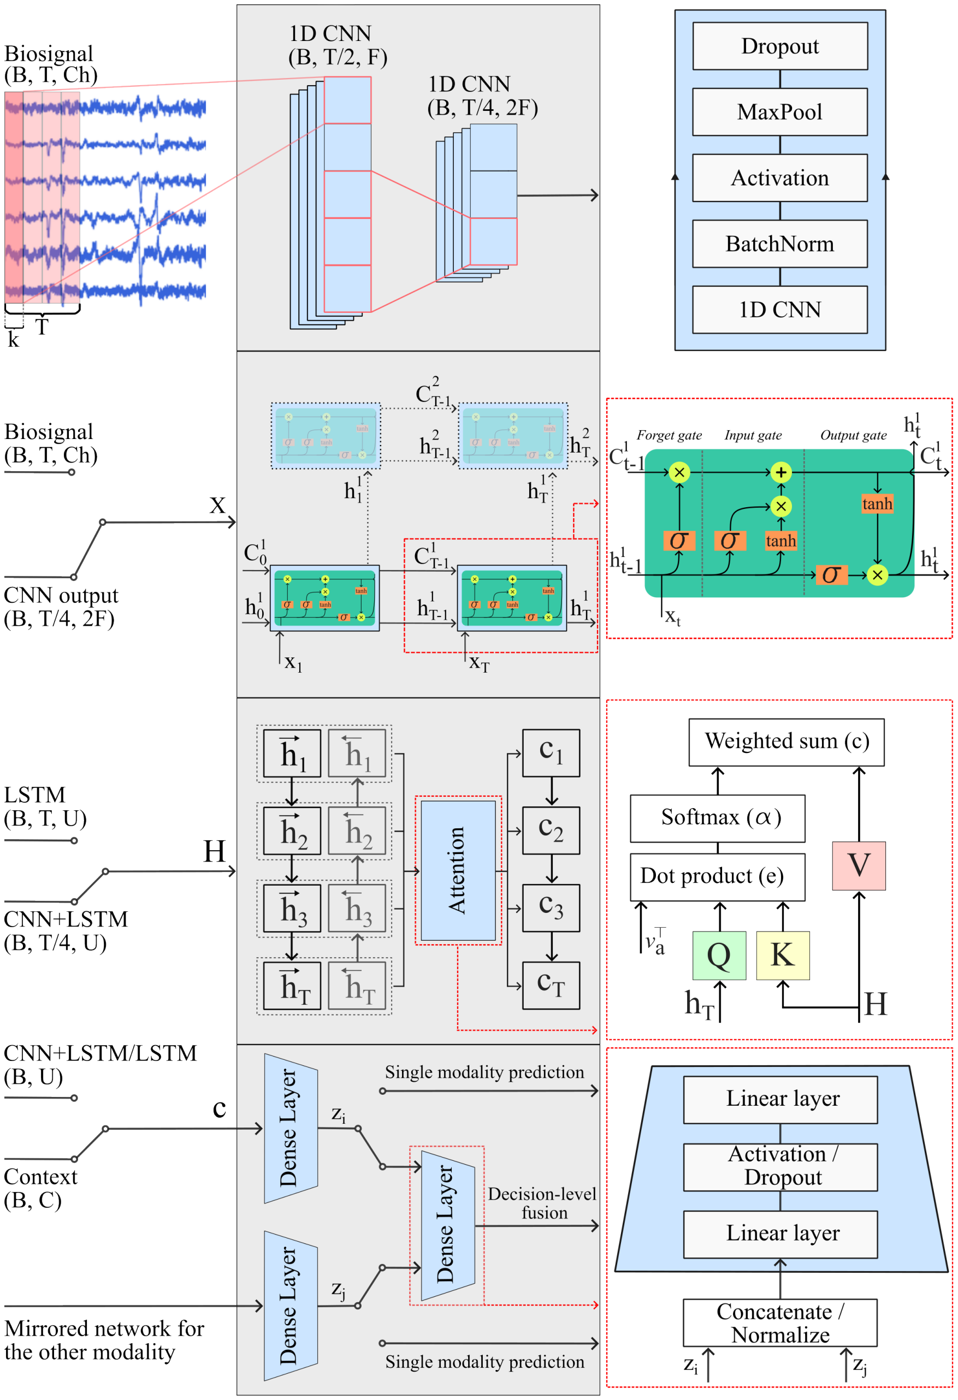
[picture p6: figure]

Figure 5. Left window shows the input sequence along dimensionality, where: B: batch size, T: sequential data samples, Ch: sensor channels, F: CNN filters, D: bidirectional scalar, and U: hidden units. The middle grey boxes are the network flow from input to output. The right window highlight components within the network.

# Hyperparameter Optimization and Training Strategy

Arbitrarily choosing the best model configuration settings is nearly an impossible task and leads to

suboptimal results, because the configuration varies depending on the dataset and networks. Instead,

Bayesian search is recommended for hyperparameter optimization Lashgari et al 2021. It explores the

hyperparameter search space, learning a distribution of hyperparameters, which provides the lowest

validation loss and exploits those ranges to optimize the model configuration. Table 3 shows the search

space of interest. The LSTM utilizes the hidden units, bidirectional, and layers. The CNN includes kernel

size and filters. Additional hyperparameter are dedicated to the optimizer (AdamW) and dense layers.

Table 3. Hyperparameter search space.

Hyperparameter | Range | Type
Learning rate | (10−5 , 10−3
| ) | Continuous
Weight decay | (10−5 , 10−3
| ) | Continuous
Dropout | (0.1, 0.4) | Continuous
Batch size | (16, 32, 64, 128) | Ordinal
Dense ratio | (0.25, 0.5, 0.75, 1.0) | Ordinal
Hidden units | (32, 64, 128, 256) | Ordinal
Filters | (16, 32, 64) | Ordinal
Kernel size | (3, 5, 7, 9, 11) | Ordinal
Activation | (ReLU, ELU) | Choice
Bidirectional | (False, True) | Choice
Layers | (1, 2, 3) | Choice

For each model architecture, the search algorithm ran for 100 different hyperparameter settings. Each

configuration were trained for 250 epochs using an early stopping condition, where the criteria for early

stopping was decided to be when 25 continuous epochs did not improve validation loss.

All models were trained using a version of the train-validate-test split strategy for both subject-

dependent and subject-independent classification. Subject-dependent classification can be seen as a

tailor-made network to a single user, highlighting the models ability to learn individual patterns, and

excels when inter-subject variability is an issue. The partitioning split ratio was set to 70/15/15% for

the whole dataset.

In contrast, subject-independent classification focuses on general patterns from multiple subjects,

highlighting the models robustness and ability to generalize across unseen subjects. Given the 17

participants, the partitioning split ratio was set to 14/2/1 subjects. This strategy is also called leave-

one-subject-out.

Regardless of the train-validate-test split version, the biosignal dataset structure had the dimen-

sionality of (B, T, Ch). Although the sequential data samples (T) varies depending on the modality, a

prefixed window length of 3 s, corresponding to a full trial period, is chosen for the offline inference

model to allow for richer context. This serves to set a baseline for the ideal condition, allowing the

model to capture the transition patterns and channel relationships before evaluating the system under

the stricter operational constraints required for real-time deployment.

To validate performance across all subjects, the split strategy incorporates a K-fold cross validation,

where K = 8. For every set of hyperparameter settings, eight folds of training of completely new

models are executed. For each fold, two random participants are allocated to the validation set. Once all

folds are complete, a final model is trained on all participants except for one held-out individual, who

serves as the independent test set.

During the training procedure, precautions against data leakage must be addressed. Data leak-

age occurs when information from outside the training dataset is accidentally used to create the model,

or when features of the validation and test splits leak into the training pipeline. The effect is silent

and causes models to present accurate, but generalize worse. Two data leakage trends was discovered

during the development. For subject-dependent, the three periods within one trial needs to be grouped

together, ensuring no leakage of trial-level information appear in one of the other splits (Lemoine

et al 2023). The other trend is subject-level leakage and was avoided by dividing subjects to a specific

split (Brookshire et al 2024).

Training strategy: For the first 75 iterations, hyperparameters are randomly sampled before optimiza-

tion begins. Each configuration is trained for up to 250 epochs or until early stopping is triggered, with

validation performed after every epoch. During training, a forward pass is executed each epoch, passing

the biosignals through the network and dense layers to produce logits.

Afterwards, a loss function (cross-entropy loss) is executed to measure the error across predicted

probabilities and true labels. The loss assists the model to become more confident by rewarding correct

answers and penalizing wrong answers. A lower loss value suggests that the model assigns a high

probability to the correct class and low probabilities to the incorrect classes. The loss is used to back

propagate though the network leading the a gradient, which determine how weights and biases in the

network contribute to the error, and which adjustments are needed to reduce it. An analogy, is that the

loss function presents a curvature/landscape, where we want to descend to lower levels of the landscape

to acquire a lower loss, and the gradient is our map showing which direction to travel.

Updating the weights and biases are done by an optimizer, which interpret the gradient attributes and

adjusts the weights and biases accordingly. The optimizer used is the adaptive moment estimation

with weight decay (AdamW), due to its properties of momentum and weight decay, it have shown

promising results compared to other methods, like stochastic gradient descent with momentum and

Adam (Loshchilov and Hutter 2017). Momentum ensures accelerating and maintenance of the gradient

descent process resulting in faster convergence and exits from saddle points, local minima and local

maxima in the curvature. The weight decay property ensure better generalization, by decouple weights

from the gradient update step, it penalizes large weights to also relay on smaller weights to capture

underlying patterns instead of focusing on specific dominant patterns, which can cause overfit.

# Transition to Real-Time Model Deployment

Once the ideal offline inference conditions, network architectures, and modality performance are

established in Section 4.3 (Subject-Independent Classification), the top-performing configuration is

selected for further evaluation. This architecture and modality combination is then integrated into

an online inference framework and the performance will be detailed in Section 4.4, which showcase

the real-time model deployment and scalability, and Section 4.6 ultimately demonstrates the model’s

generalization and capability for exoskeleton control. The remainder of this section details the key

component modifications required to transition the system from offline to online inference. Firstly, the

training strategy must align with the operational properties of real-time inference. In other words, the sequence length used during model training must match the live data-stream inputs. This design choice

represents a trade-off between temporal context and system latency. Through empirical and rational

reasoning, a historical buffer containing 500 ms past information, was selected as a feasible balance for

accurate classification. Coupled with an inference interval of 100 ms, new data samples are gathered

every 100 ms to trigger a new classification. This is achieved using a sliding window that increments

every 100 ms, creating an overlap between past and present data. Therefore, during dataset preparation

for model training, the data is segmented using this sliding window approach and processed via the

pipeline detailed in Section 2.6, bypassing the standard 3 s trial-period segmentation.

Segmenting the original 3 s trial period using this sliding window yields a total of Nw windows,

calculated according to Equation 2.1:

Nw =

N − W

S

+ 1 | (2.1)

where N is the total number of samples within the 3 s trial, W is the window size (corresponding to

500 ms of samples), and S is the step size (corresponding to 100 ms of samples).

Each generated window must be assigned a ground-truth class label. While windows entirely within

the rest period were uniformly labeled as ‘rest’, windows spanning the onset and offset boundaries

presented a risk of label noise. Due to participant reaction time, the early portion of a movement

trial physically resembles a resting state, and a similar transition occurs during the offset period (see

Figure 4C). To mitigate mislabeling, an automated labeling threshold was implemented. Windows

within the onset period were only labeled as ‘onset’ once the EMG signal’s window mean positive

slope value exceeded the baseline noise floor calculated from the rest period. Conversely, during the

offset period, windows were labeled as ‘rest’ once the negative slope returned to the baseline mean value.

The training strategy remains unchanged and follows the subject-dependent partitioning split ratio of
70/15/15 %.

Figure 6 displays the model inference pipeline. Data is acquired every 100 ms and transferred into

a circular buffer, displacing the oldest samples. Once the buffer is fully initialized with 500 ms of

historical data, the data vector is extracted and preprocessed. The deployed model processes this input

to perform classification, forwarding the class with the highest logit value to majority voting.

During real-time system evaluation, the raw model classifications tended to oscillate between ‘onset’

and ‘offset’ states every 100 – 300ms once a full flexion posture was reached. This oscillatory behavior

(visible in Figure 4C, left, between 3 – 6s) was likely caused by variations in sensor placement and the

physical force applied during sustained flexion, causing the model to misinterpret descending signal

slopes as intentional extensions. Without further logic, the exoskeleton would continuously contract and

release the mechanical fingers in response to this instability. To mitigate this, a post-processing stage

incorporating majority voting, priority scaling, and confidence rejection was implemented between the

model output and the exoskeleton controller. This logic collect the five most recent model classifications

into a secondary circular buffer. For each new inference cycle, the majority class is determined. If the

average model confidence for this majority class exceeds a 90% threshold, the decision is forwarded to

the exoskeleton, otherwise the classification is rejected. Furthermore, to handle directional transitions

smoothly, whenever a flexion class (‘onset’) is active, its corresponding extension class (‘offset’) is

scaled in selection priority by a factor of two, ensuring rapid, stable transitions when the user intends

to extend that specific finger.

# 2.7. Control Architecture

SoFiE and the model inference pipeline are implemented as two separate modules that can communicate

and enables the model to control the exoskeleton, as illustrated in Figure 6. The complete system is

arranged using a TCP client/server architecture, where the model inference pipeline acts as the client

and the exoskeleton acts as the server. On the client side, biosignals are acquired, stored in a circular

buffer, preprocessed, and classified by the model. A majority-voting step is then used to stabilize the

classified motion before an actuation command is sent to the exoskeleton. During operation, the client

also receives the current system state and sensor feedback from SoFiE, allowing the inference pipeline

to be aware of the physical state of the device, keeping it from overwriting an ongoing motion. On

the exoskeleton side, the ESP32 microcontroller handles communication and interfaces with the motor,

sensors, and supporting electronics that make up the SoFiE control unit. When the microcontroller

receives an actuation command, it checks the internal system state and, if ready, applies the desired

actuation to the micro DC motor, which retracts or releases the primary tendon through the spindle.

To ensure that the motor reaches the desired position, the integrated motor encoder is used to track the

current motor position. This also enables a software limit to keep the motor within a predefined range and

prevent over-tightening of the tendons, which could otherwise cause discomfort for the user. MagSense

is continuously sampled during operation, providing tactile feedback from the index fingertip to detect

contact and infer interaction with external objects. A threshold is implemented such that actuation is

stopped when the MagSense signal exceeds a predefined value, indicating contact with a solid object

or a sufficiently stable grasp. StretchSense is also sampled during actuation; however, its signal is not

used directly for real-time control in the present implementation, but is instead used after operation to

evaluate the deformation of the actuated digit. During runtime, SoFiE sends the captured sensor data

and system state back to the client, allowing the model inference pipeline to monitor the behavior of the

exoskeleton. The exoskeleton currently uses a variation of a bang-bang controller, where the input is the

actuation command from the model inference pipeline and the control target is either the motor position

or the MagSense threshold. This controller provides a simple and robust first step for proof-of-concept

validation, while alternative control strategies will be discussed in Section 5 (Latency and Controller

Logic). Keeping the model inference pipeline and the exoskeleton as independent modular units allows

each system to be developed, tested, and validated separately before being integrated into the complete

control architecture.

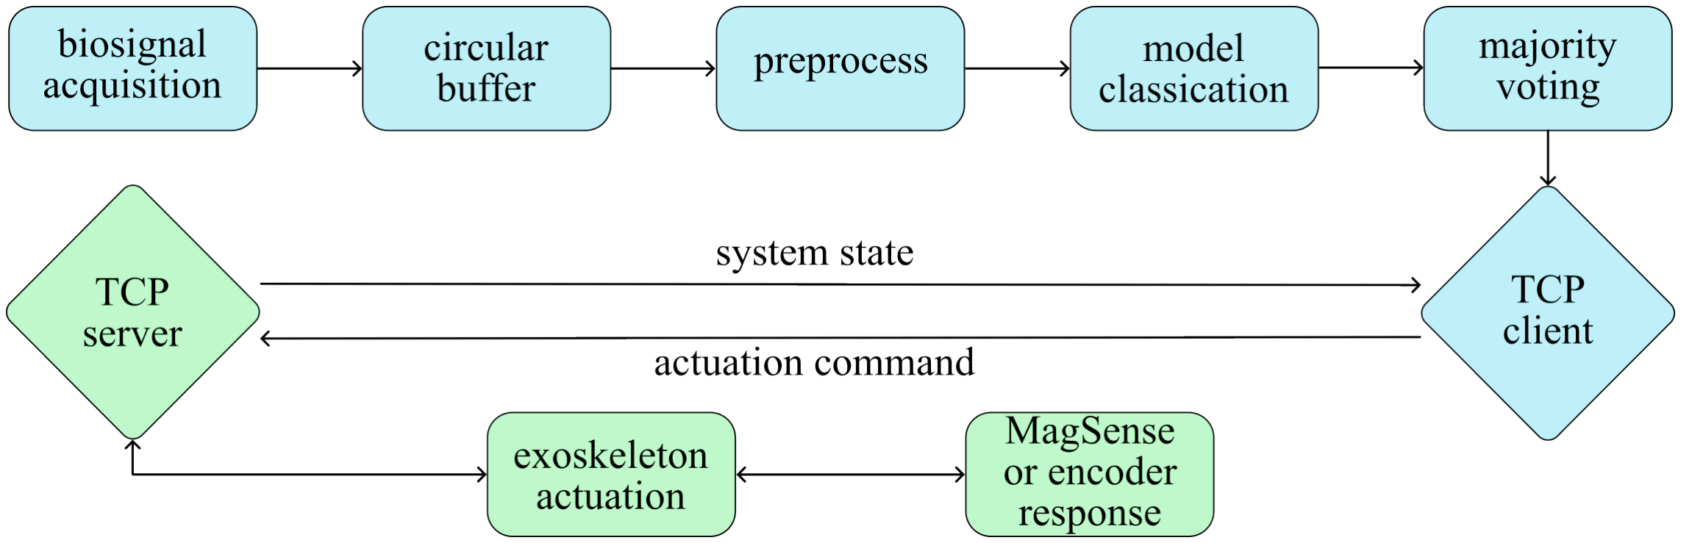
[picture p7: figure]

Figure 6. System diagram of the TCP-based control architecture. The client acquires and preprocesses biosignals, performs model inference, stabilizes the output using majority voting, and sends actuation commands to the server (SoFiE). The server receives the commands, actuates the exoskeleton, monitors MagSense and encoder feedback, and returns the current sensor data and system state to the client.

# 3. Experimental Methodology

This section describes the experimental procedures used to evaluate the proposed system. The experi-

ments were designed to characterize the integrated exoskeleton sensors, assess the grasping capability

of the mechanical platform, evaluate the biosignal classification pipeline, and demonstrate real-time

control of the exoskeleton. First, StretchSense and MagSense were tested independently to examine

their mechanical and sensing behavior. The index-only exoskeleton configuration was then used to eval-

uate sensor responses during grasping of everyday objects. Finally, EEG and EMG data were collected

to train and evaluate the classification models, followed by real-time demonstrations of hand-motion

classification, muscular-effort reduction, and model-based control of the index and thumb assisting

exoskeleton.

# 3.1. Characterization of Integrated Exoskeleton Sensors

For the characterization of the integrated sensors (StretchSense and MagSense) the version of SoFiE

with only the index finger module was used.

# StretchSense

To characterize the StretchSense sensor and find the optimal thickness, five different thicknesses of the

same design was printed and tested. The thickness started at 0.5 mm and incremented in steps of 0.5 mm

up to 2.5 mm. Each spring was printed on a Prusa MK3s with a layer-height of 0.1 mm for better height

accuracy and layer-adhesion. The filament handling and printing parameters were otherwise kept to

what was suggested by Recreus, the maker of the conductive filament used. The springs were tested

using a universal testing machine (EZ Test, Shimadzu). The universal testing machine, is able to either

press or pull a specimen with high displacement accuracy. For the tests of StretchSense, the maximum

change in displacement was measured on the subject’s hand on which the sensor was meant to be used.

Measuring the distance from the metacarpophalangeal (MCP) joint to the tip of the distal phalanx (the

fingertip), when the index finger was fully stretched and when fully contracted, yielded a displacement

on the dorsal side of 40 mm. This was therefore chosen as the maximum distance that the spring was

stretched during testing.

On the universal testing machine, a 100 N load cell was rigidly mounted on the top arm, for high

precision force measurements, later used to produce a stretch-strain curve and to see the relationship

between force, stroke and resistance of the sensor, which will be shown in Section 4.1 (StretchSense).

To measure how the electrical resistance of the spring changed during stretching and relaxation, an

LCR meter (LCR-6100) from RS PRO was interfaced with the ends of the spring via a dedicated test

fixture. In each end of the spring a wire was inserted during printing to securely fasten it to the spring.

The test fixture then with alligator clips, attached to these wires to measure the resistance change.

An illustration of the protocol can be seen on Figure 7A. StretchSense was mounted in a 3D-printed

fixture designed for the universal testing machine and then pre-tensioned to 0.15 N to remove any slack

in the beginning, the position and force were then zeroed at this point. The universal testing machine

was then set to do 31 cycles where each cycle consisted of going from 0 mm to 40 mm, then back

to 0 mm. A 5 s hold was set at the zero position at the end of each cycle to allow for the material to

contract. The springs were cycled at a constant rate of 1 mm · s

−1
Data acquisition | from | the universal testing machine was done through a National Instruments

Data Acquisition unit (NI DAQ), which captured the analog force and displacement signals and con-

verted them to digital values. These data streams, along with the digital resistance reading from the

LCR meter, were processed and synchronized in real-time using a custom MATLAB script. For post

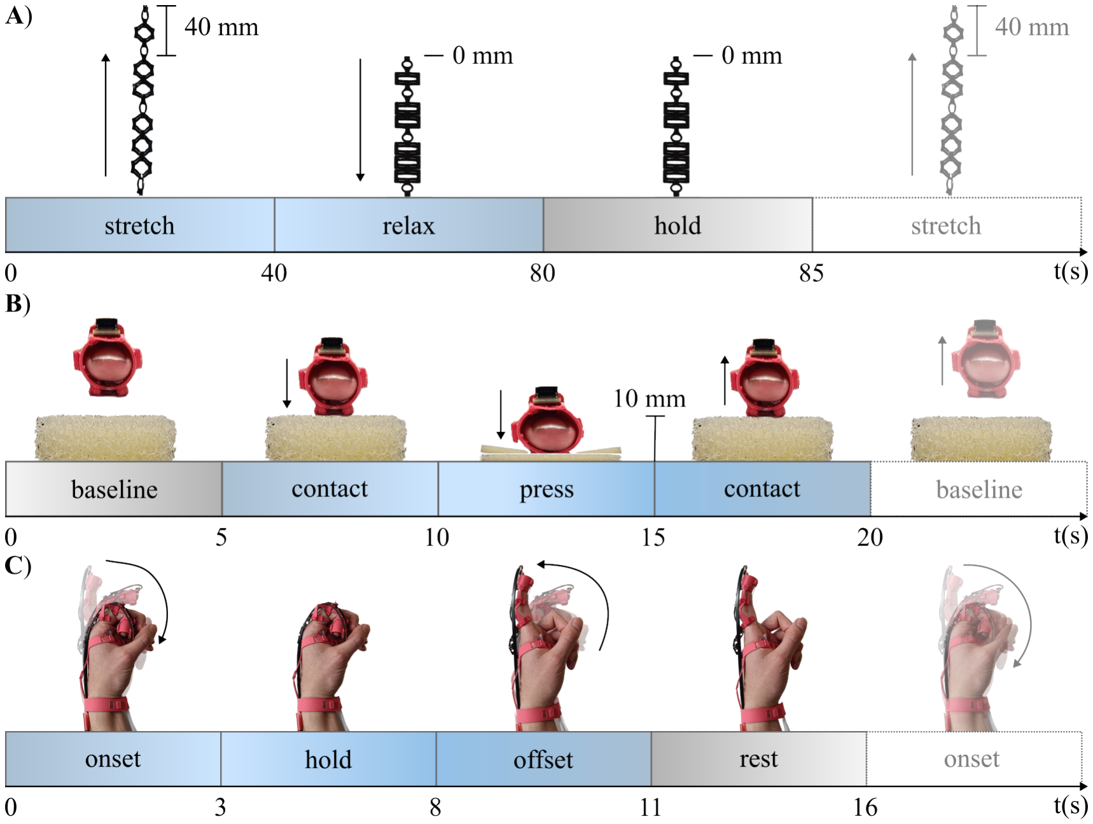
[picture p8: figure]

Figure 7. A illustrates the experimental protocol for a single cycle of StretchSense on the universal testing machine with timestamps and end position. B illustrates the protocol for a single trial of the MagSense characterization. MagSense is held away from the foam, then placed to get the contact data, then pressed 10 mm into the foam and held there, then relaxed back to contact, and lastly returned to baseline. C illustrates how the relationship between StretchSense and the motor position was tested using the active exoskeleton, with onset, being contraction of the index finger, and offset being relaxing and returning to rest position.

processing, the first cycle of each test was discarded as a "burn-in" outlier to account for initial material

settling. The remaining 30 cycles were averaged to determine the mean and standard deviation of the

force and resistance as a function of displacement.

The spring chosen for final integration was subjected to an extended test, to asses its long-term perfor-

mance and transient behavior. This test followed the same protocol as before, but was extended to 501

cycles instead of 31. The experimental setup can be seen in Supplementary Information Figure S2.

# Actuator Response with StretchSense

Figure 7C illustrates a trial for testing the motor position and StretchSense relationship. The motor was

set to actuate to the exoskeletons maximum contraction of 3 rotations or ~19 rad. The encoder position

and the voltage shift caused by the resistance change of StretchSense was recorded during 10 trials of

16 s each. Each trial consisted of an onset period, where the exoskeleton actuated the index finger to its maximum contraction, then the exoskeleton held its position for 5 s, allowing the measurements to

stabilize. Then a offset period where the exoskeleton released the tension of the tendons, allowing the

index finger to return to its rest position, which was then followed by 5 s of rest to again, let the signals

stabilize. The encoder position was converted to a rotation in radians using Equation 3.1:

Prad = Cencoder ·

2 · π

CPR · GearRatio

, | (3.1)

where the position in radians Pr ad is the current counted ticks of the encoder Cencoder multiplied with

a fraction, that converts from encoder ticks to a rotation in radians. Since the encoder measures motor

rotations rather than output-shaft rotations, the gear ratio is used to scale the encoder output. CPR is the

amount of counts or per rotation of the motor also known as the the encoder resolution. For the Pololu

motor used in SoFiE, CPR is 12, as there is 6 rising and falling edges in the signal from both encoder

pin A and pin B per rotation of the motor. The voltage from StretchSense is converted to a resistance

using Equation 3.2:

RStr et cℎSense =

R1 · (Vs − Vmeasur ed)

Vmeasur ed

(3.2)

where the source voltage (Vs) is 3.3 V supplied by the ESP32. The known resistor R1 is 1 kΩ. The

voltage is measured using an ADC pin on the ESP32 with 12 bits of resolution. The voltage is filtered

using a 4th order butterworth low-pass filter with a cutoff frequency of 1 Hz to isolate the low frequency

changes caused by moving the finger, instead of high frequency electrical noise.

# MagSense

Characterization of MagSense was done by testing against three Polyuethane (PU) foams of different

densities or pores per inch (PPI). The three foams were cut into 30 mm by 30 mm squares with a

thickness of 20 mm and placed in a 3D printed test fixture that both held the foams and acted as a

mechanical stop for the test. The test was done by following a five step protocol (which is also illustrated

on Figure 7B) with a total time of 20 s with each step being 5 s. First, a baseline of 5 s where the user

is just hovering over the foam, then 5 s of contact with the foam where the MagSense is placed on the

foam. The next 5 s, is where MagSense is pressed 10 mm into the foam and held there using the test

fixture as a mechanical stop for the finger to rest against to ensure equal compression for all the tests.

Then the compression is released and the sensor is brought back to contact with the foam and held

here for 5 s. At the end, the sensor is lifted back to baseline. The test were repeated 10 times for each

PPI. Afterwards, the measurements were filtered using a 4th order butterworth filter, removing the high

frequency noise, after which they were split into trials and baseline corrected.

# 3.2. Object Grasping using Index Module

To demonstrate how the StretchSense and MagSense sensors respond during assisted and passive

grasping, five demonstrations were performed with five different everyday objects. The five objects

were a 500 mL water bottle, pencil, sponge, screwdriver and a pouch filled with pencils. These objects

represent a range of physical properties. Some are rigid and thin while others are bulky or soft, demanding

different degrees of index finger flexion to achieve a stable grasp. For the demonstrations, the objects

were placed on a flat and stationary surface and the grasp performed was a pinch between the thumb

and the index finger. The motor was set to run until it either hit its rotation limit of about 19 rad, or

MagSense reports a higher value than 5 G. Meanwhile, StretchSense is read and converted to relative change to see if there is a difference in travel of the index finger between the different objects. This

demonstration follows the same protocol as the actuator response test protocol mentioned earlier.
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

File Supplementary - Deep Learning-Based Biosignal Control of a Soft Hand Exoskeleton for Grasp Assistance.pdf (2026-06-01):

## Deep Learning-Based Biosignal Control of a Soft Hand Exoskeleton for Grasp Assistance Supplementary Information

Magnus Malthe Sigsgaard Nielsen¹

, Nicklas Nikolaj Grønvall¹

, Xiaofeng Xiong*¹
and Saravana
Prashanth Murali Babu*¹

1SDU Biorbotics, SDU Soft Robotics, University of Southern Denmark, Odense, 5230, Denmark E-mail: xizi@mmmi.sdu.dk, E-mail: spmb@mmmi.sdu.dk.
*Supervisor.

Exam numbers: Magnus Nielsen: 182180190 ; Nicklas Grønvall: 4110717

Exam project: Master thesis (Robot Systems) (Drones and Autonomous Systems)

Date of Submission: June 1, 2026

This Supplementary information includes:

S1. EEG Channel Selection and Spectral Analysis
S2. Experimental Setup for Characterization of StretchSense S3. Experimental Setup for Index and Thumb Classification S4. Supplementary Videos
S5. Link to GitHub
S6. Contributions

S1. EEG Channel Selection and Spectral Analysis

This section details the EEG spectral analysis and justifies the selection of the central and frontal regions across the delta–beta frequency bands to identify which channels and frequency bands contained the most discriminative information. The Power Spectral Density (PSD) was computed using the processed EEG method according to Section 2.6, EEG preprocessing. However, for this specific analysis, the bandpass filter was extended to 0.5 – 60 Hz to capture the full spectrum of interest. Following the international 10 – 20 system, the electrodes were grouped into five regions: pre-frontal (Fp1, Fp2), frontal (F7, F3, Fz, F4, F8), central (C3, Cz, C4), temporal (T3, T5, T6, T4), partial (P3, P4). The analyzed frequency bands included delta (0.5 – 4 Hz), theta (4 – 8 Hz), alpha (8 – 13 Hz), beta (13 – 30 Hz), gamma (30 – 60 Hz). For each participant, the PSD was computed across all trials and grouped by class (c ∈ [rest, onset, offset]), region (r), and frequency band ( f ). The absolute band power (Ec,r, f ), was obtained by integrating the single trial PSD using the trapezoidal rule. The absolute band power was normalized to reduce inter-subject variability, which we will denote as relative power (Erelative). The relative power was calculated by dividing the specific band power by the total power across the entire spectrum of frequencies (0.5 – 60 Hz):

Erelative =

Ec,r, f

Ec,r,0.5–60

(S1)

Finally, the relative power (shown in Eq S1) were averaged across all trials within each class to obtain a single robust metric per participant, region and frequency. The average relative power is measured as amplitude squared per unit of frequency and can be observed in the Figure S1A mesh grid. These participants was chosen to highlight inter-subject variability. However, a general observation regarding all 17 participants, showed that the highest relative power appeared in prefrontal region for delta band, alpha in parietal region, and beta in central region.

To investigate which regions and frequency bands contribute with strong class separation, Cohen’s d was calculated, as defined in Eq S2:

d =

x¯1 − x¯2
√︂

s

2
1
- (n1−1)+s
2/2· (n2−1)

n1+n2−2

(S2)

where, x¯1 and s1 are the estimated mean and standard deviation of the relative power across trials at one specific region and frequency band in the first class, whereas x¯2 and s2 is the equivalent metrics for a other class. The variables n1 and n2 denote the corresponding number of trials per class. The Cohen’s d formula were computed across all participants and averaged to yield a global class separation influenced by all participants. Figure S1B illustrates these Cohen’s d values. The result indicates the strongest class separation belong within the central and frontal region across delta, alpha, and beta frequency bands for both the rest vs onset and rest vs offset conditions. However, a weak class separation appears in onset vs offset condition. Indicating how the relative power remain similar between the initialization of a finger flexion motion and its return to an idle state.

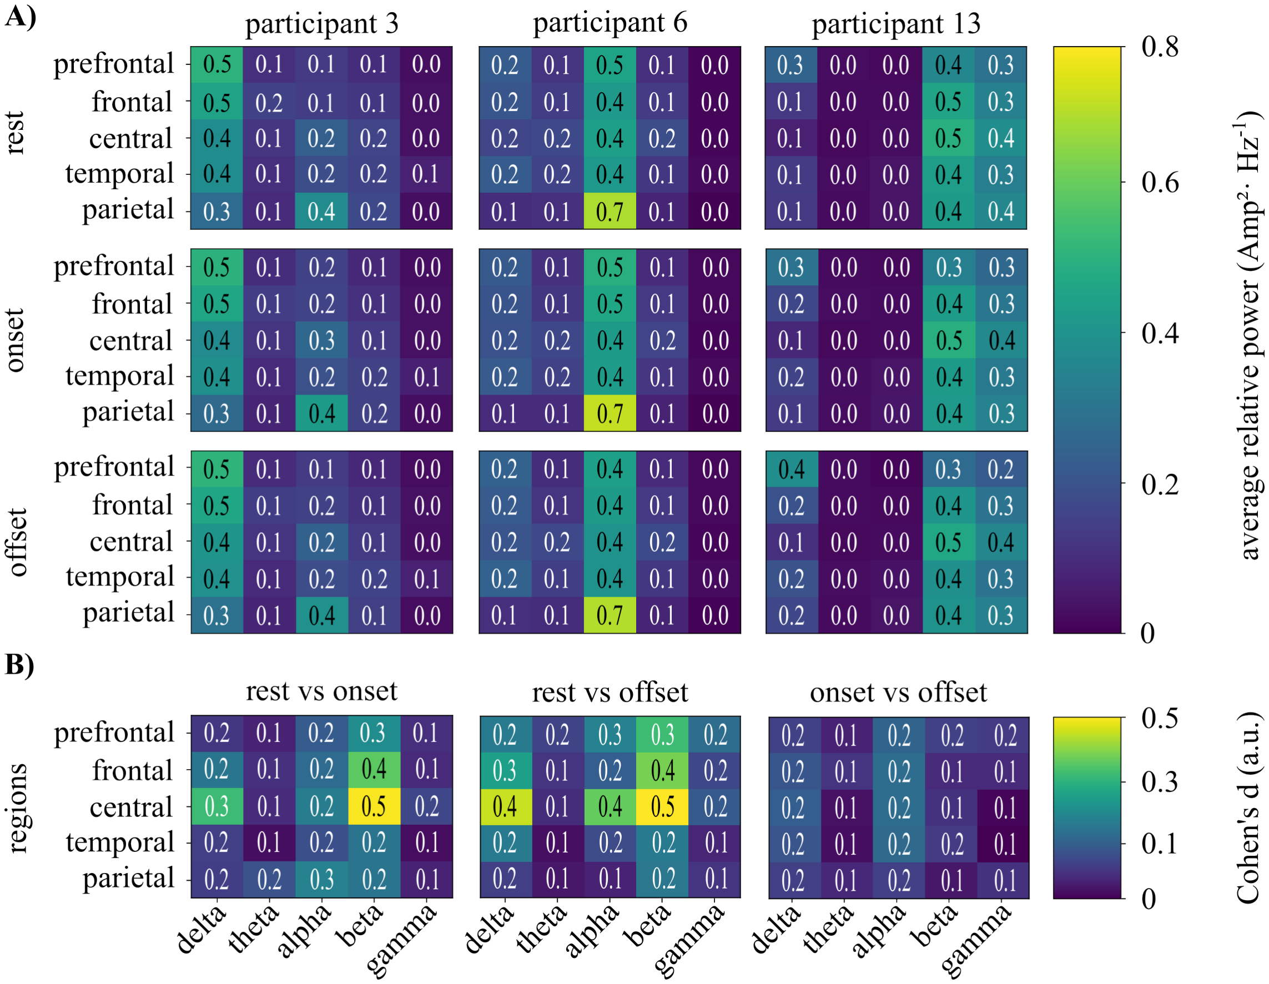
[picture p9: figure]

Figure S1. A shows the power density spectrum (PSD) across regions (prefrontal, frontal, central, temporal, and parietal) and frequency bands (delta, theta, alpha, beta, and gamma) for three participants with strong dissimilarity in PSD. Each row present the classes of index and thumb onsets, offsets, and resting state. B displays class separation (rest vs onset, rest vs offset, and onset vs offset) using Cohen’s method, based on the PSD for all 17 participants across regions and frequency bands..
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

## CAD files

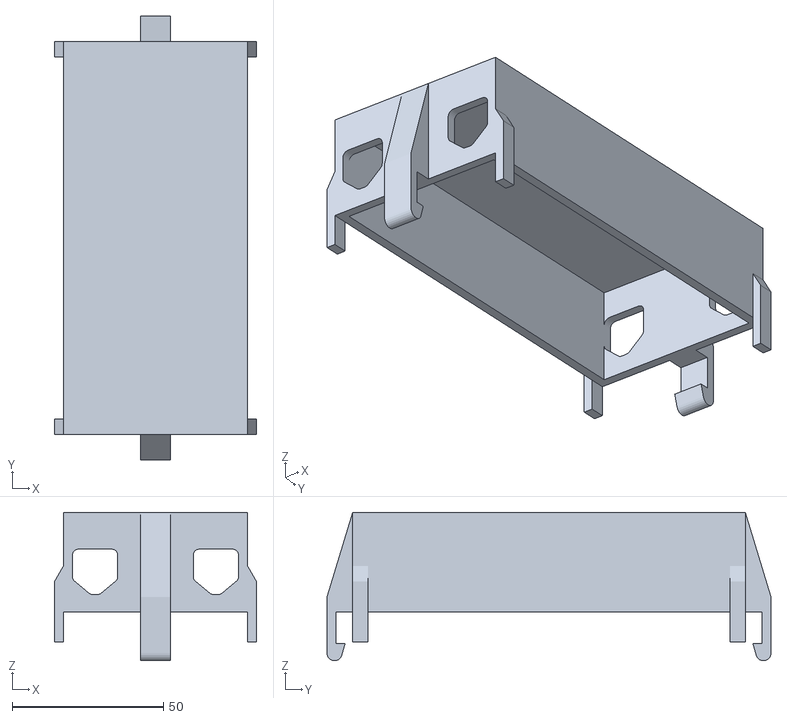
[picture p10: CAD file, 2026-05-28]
Exoskeleton files/Enclosure/Enclosure lid.stl
67.0 x 147.0 x 49.1

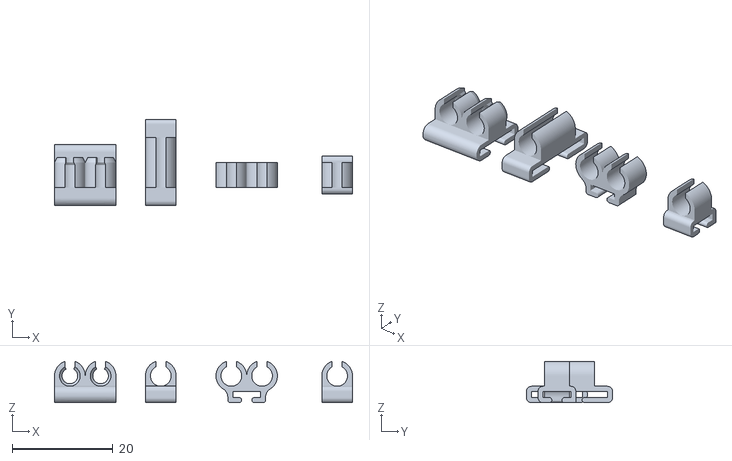
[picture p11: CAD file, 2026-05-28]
Exoskeleton files/Index and thumb version/Hand/PTFE_clamps.stl
59.1 x 17.1 x 8.18

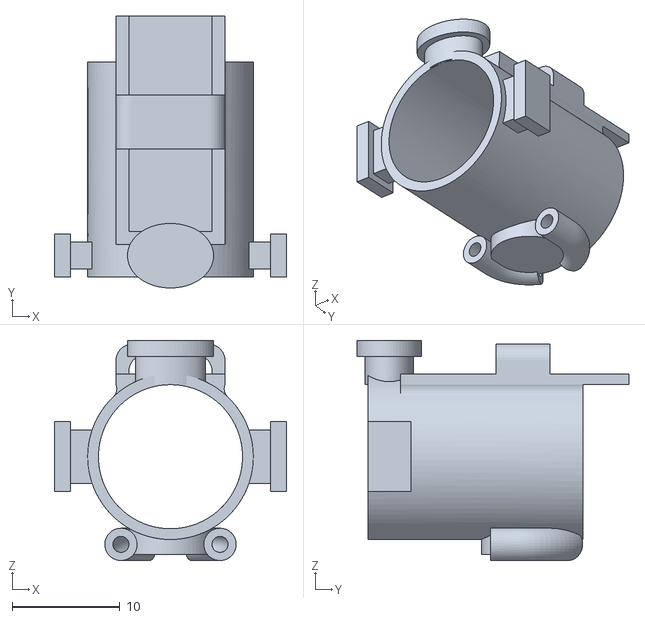
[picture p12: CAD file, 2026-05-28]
Exoskeleton files/Index and thumb version/Index module/IF_FT_magnet_revised.stl
21.6 x 25.2 x 20.4

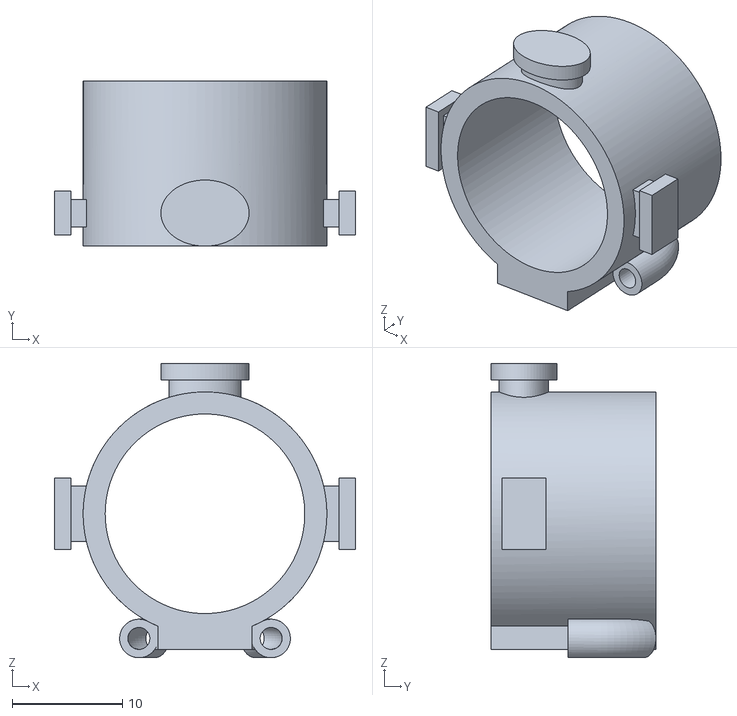
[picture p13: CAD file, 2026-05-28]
Exoskeleton files/Index and thumb version/Thumb module/Thumb_FT_revised.stl
27.3 x 15.0 x 26.7

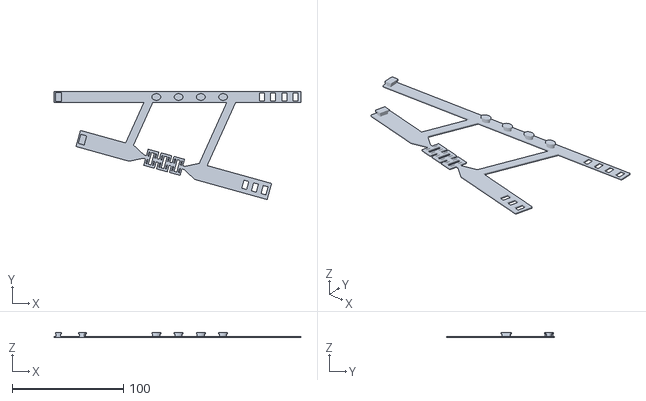
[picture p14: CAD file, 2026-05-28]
Exoskeleton files/Index only version/Hand/Hand_strap.stl
222.0 x 97.2 x 4.80

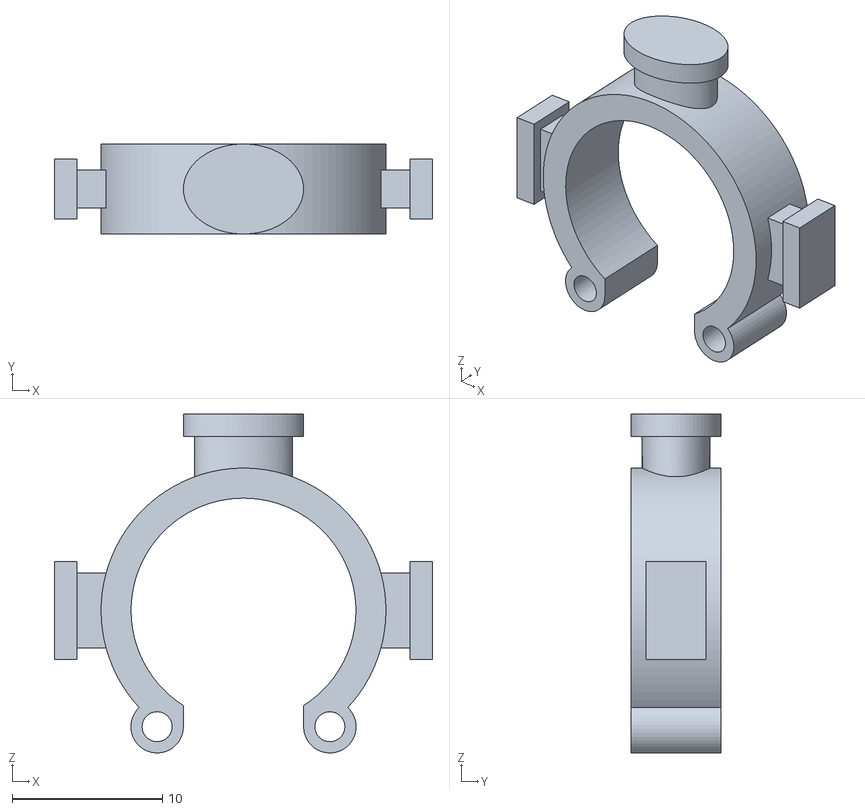
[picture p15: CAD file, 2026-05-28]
Exoskeleton files/Index only version/Index module/IF_S2_Phalange_ring.stl
25.2 x 6.00 x 22.6

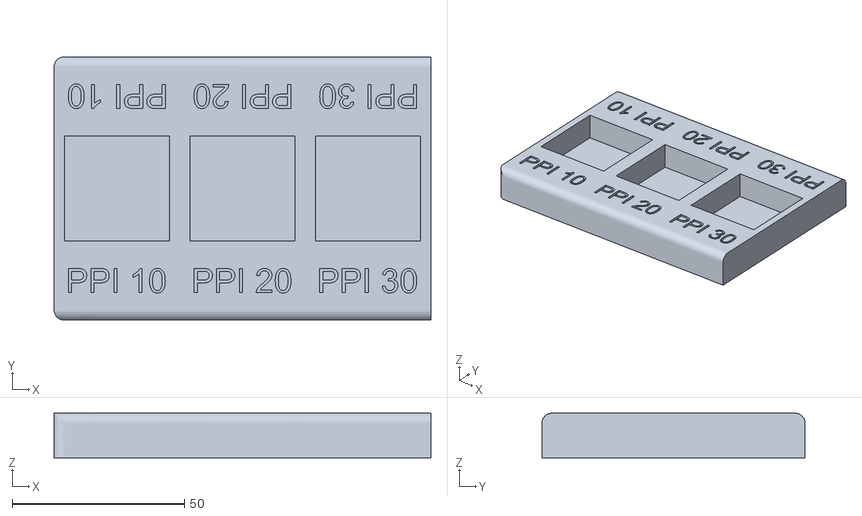
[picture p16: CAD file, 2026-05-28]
Exoskeleton files/Miscellaneous/Foam test.stl
109.5 x 76.5 x 13.0

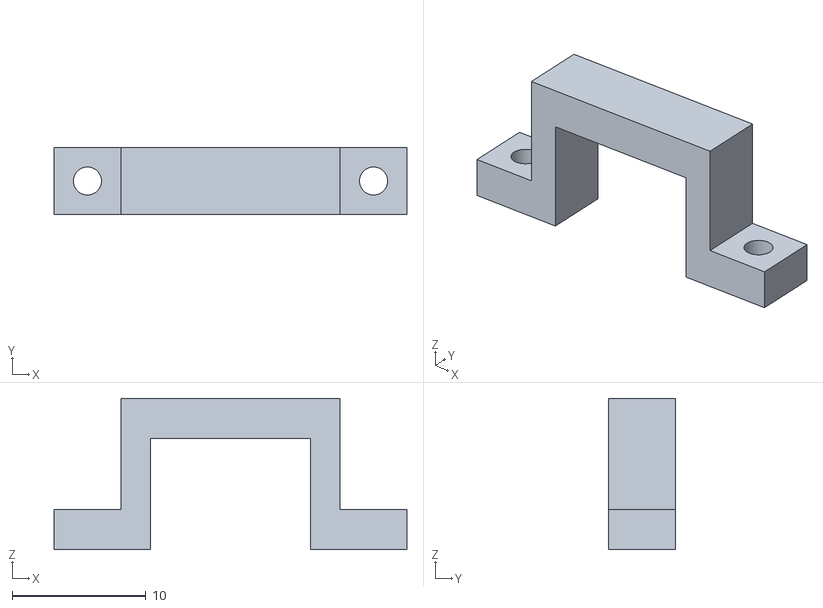
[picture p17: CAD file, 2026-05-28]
Exoskeleton files/Enclosure/motor_clamp.stl
26.4 x 5.00 x 11.3

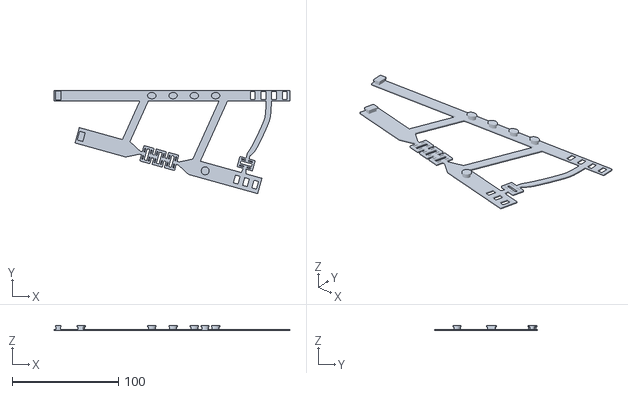
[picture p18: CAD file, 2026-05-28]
Exoskeleton files/Index and thumb version/Hand/Hand_strap_Thumb.stl
222.0 x 97.2 x 4.80

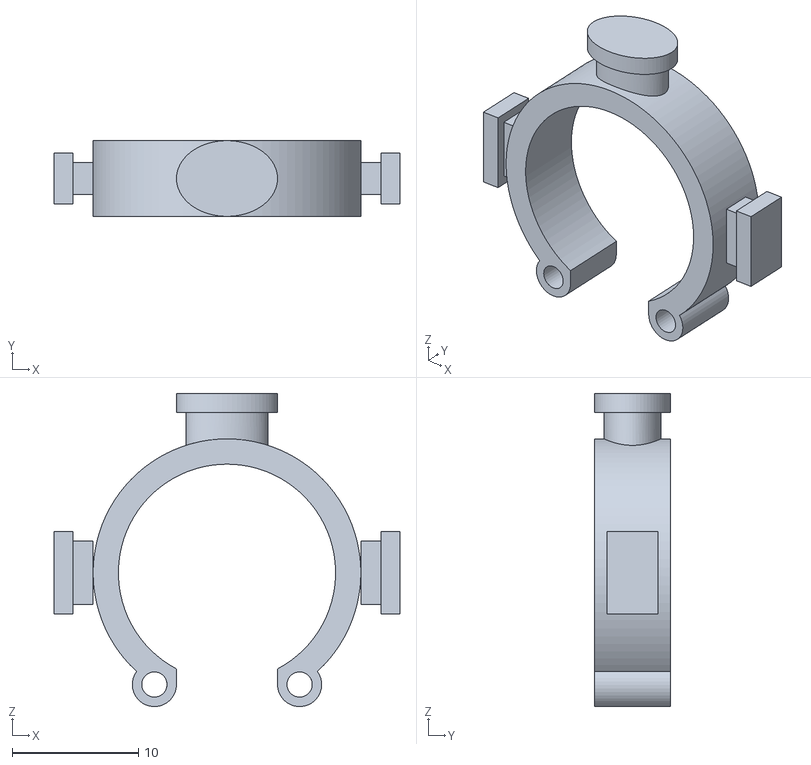
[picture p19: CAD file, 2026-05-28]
Exoskeleton files/Index and thumb version/Index module/IF_S1_Phalange_ring.stl
27.4 x 6.00 x 24.8

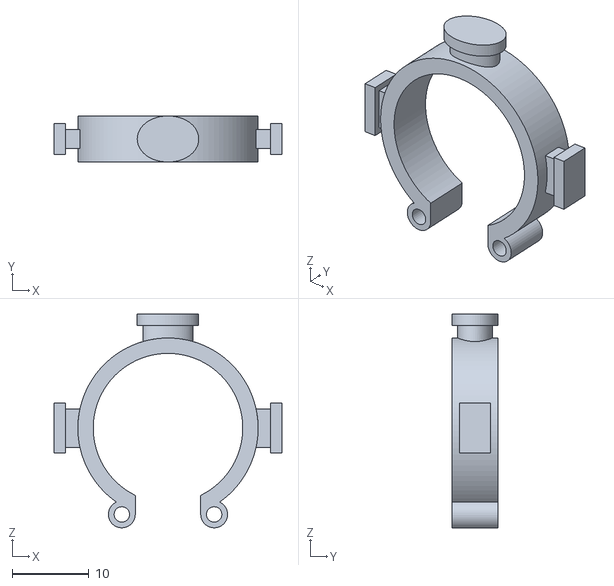
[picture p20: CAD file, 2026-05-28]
Exoskeleton files/Index and thumb version/Thumb module/Thumb_proximal_revised.stl
29.6 x 6.00 x 27.8

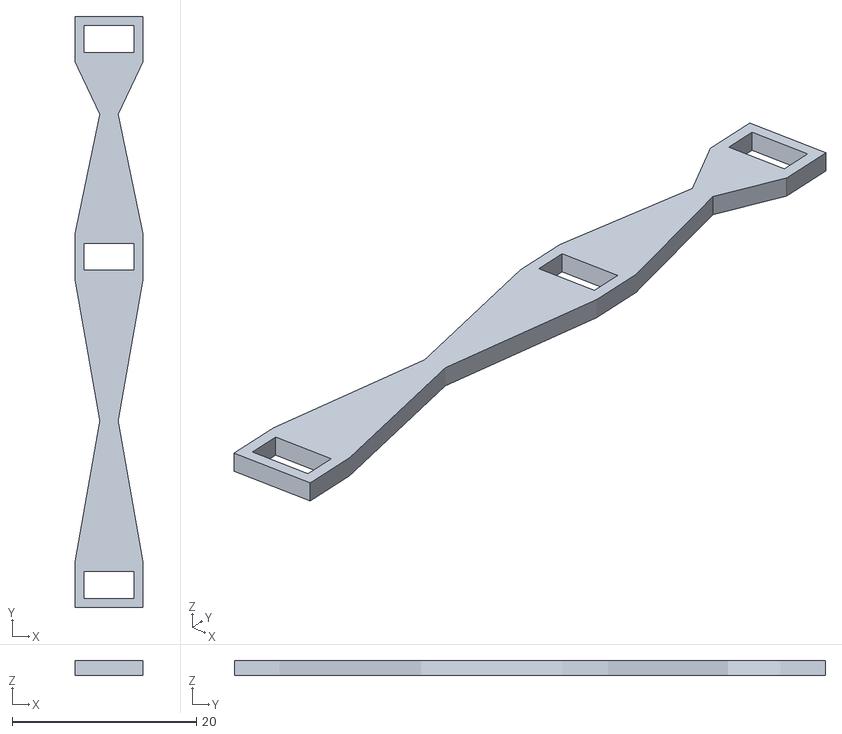
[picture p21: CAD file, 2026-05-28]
Exoskeleton files/Index only version/Index module/IF_side_support.stl
7.40 x 64.1 x 1.60

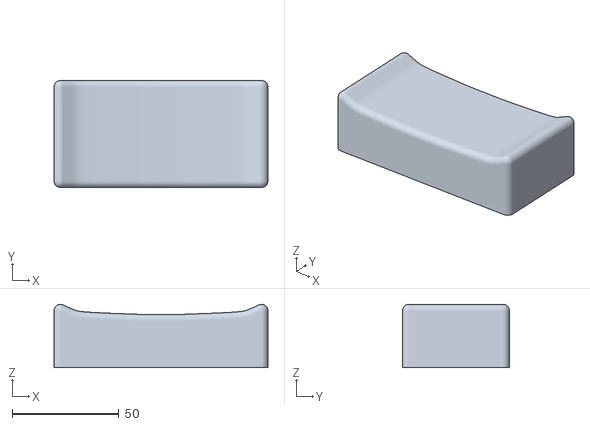
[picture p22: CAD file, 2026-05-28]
Exoskeleton files/Miscellaneous/arm_rest.stl
100.0 x 50.0 x 29.6

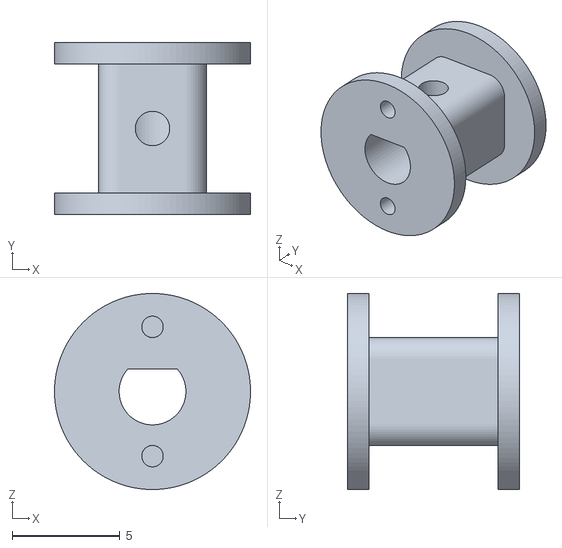
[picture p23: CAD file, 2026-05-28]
Exoskeleton files/Enclosure/spindle.stl
9.10 x 8.00 x 9.10

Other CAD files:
Exoskeleton files/Index and thumb version/Thumb module/thumb_side_support.stl
Exoskeleton files/Index only version/Index module/IF_dorsal_spring_conductive_1mm.stl
Exoskeleton files/Enclosure/Attachement plate.stl
Exoskeleton files/Enclosure/Electronics enclosure and plate.stl
Exoskeleton files/Enclosure/PTFE attachment.stl
Exoskeleton files/Enclosure/Pulley with inserts.stl
Exoskeleton files/Index and thumb version/Index module/IF_dorsal_spring_conductive_1mm.stl
Exoskeleton files/Index and thumb version/Thumb module/Thumb_dorsal_spring_revised_3_mounts.stl

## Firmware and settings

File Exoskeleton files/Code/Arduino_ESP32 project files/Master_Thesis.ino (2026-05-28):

#include "wifi_manager.h"
#include "tcp_server.h"
#include "motor_control.h"
#include "Magsense.h"

void setup() {
    Serial.begin(115200);
    connectWiFi();
    initTCP();
    initMagsense();
    initMotor();
}

void loop() {
    readCommands();
    protocolRoutine();
    checkMotorStop();
    logData();
}

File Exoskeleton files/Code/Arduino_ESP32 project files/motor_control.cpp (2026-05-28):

#include "motor_control.h"
#include "tcp_server.h"
#include "Magsense.h"
#include "config.h"

volatile long encoder_count = 0;

long target_ticks = 0;
bool motor_running = false;
bool motor_direction = true;
int max_enc = 3000; //4500

uint32_t last_log_us = 0;
uint32_t session_start_ms = 0;
uint32_t state_time = 0;

bool session_active = false;

int cycle_num = 0;
int state = 0;

int cycleMax = 3;


#define IDLE 0
#define PRE 1
#define UP 2
#define HOLD 3
#define DOWN 4
#define REST 5
#define POST 6

void IRAM_ATTR encoderISR() {
    if (motor_direction)
        encoder_count++;
    else
        encoder_count--;
}

void initMotor() {

    pinMode(AIN1_PIN, OUTPUT);
    pinMode(ENC_A_PIN, INPUT);
    pinMode(ENC_B_PIN, INPUT);

    attachInterrupt(digitalPinToInterrupt(ENC_A_PIN), encoderISR, CHANGE);

    ledcAttachChannel(AIN2_PIN, PWM_FREQ, PWM_BITS, PWM_CHANNEL_MOTOR);
    ledcWrite(AIN2_PIN, 0);
}

void stopMotor() {
    ledcWrite(AIN2_PIN, 0);
}

void moveTo(long target, bool dir) {

    motor_direction = dir;
    target_ticks = target;
    motor_running = true;

    digitalWrite(AIN1_PIN, dir ? HIGH : LOW);
    ledcWrite(AIN2_PIN, 255);
}

void protocolRoutine() {

    String cmd = getCommand();

    if (cmd == "startsession" && !session_active) {

        session_active = true;
        cycle_num = 0;
        state = PRE;
        state_time = millis();
        session_start_ms = millis();

        client.println("SESSION STARTED");
    }

    if (!session_active) return;

    uint32_t now = millis();

    switch (state) {

        case PRE:
            if (now - state_time >= 5000) {
                cycle_num = 1;
                moveTo(max_enc, true);
                state = UP;
            }
            break;

        case HOLD:
            if (now - state_time >= 5000) {
                moveTo(0, false);
                state = DOWN;
            }
            break;

        case REST:
            if (now - state_time >= 5000) {

                cycle_num++;

                if (cycle_num <= cycleMax) {
                    moveTo(max_enc, true);
                    state = UP;
                } else {
                    state = POST;
                    state_time = now;
                }
            }
            break;

        case POST:
            if (now - state_time >= 5000) {
                session_active = false;
                state = IDLE;
                client.println("SESSION DONE");
            }
            break;
    }
}

void checkMotorStop() {

    if (!motor_running) return;

    double mag_vars[3] = {0};
    readMagsense(mag_vars);
    float x_gauss = mag_vars[0];
    bool mag_triggered = (x_gauss <= MAG_THRESHOLD);

    if(motor_direction){
        if (encoder_count >= target_ticks || mag_triggered) {

            stopMotor();
            motor_running = false;

            state = HOLD;
            state_time = millis();
            if (mag_triggered) {
                client.println("STOP_CAUSE: MAGNET");
            } else {
                client.println("STOP_CAUSE: ENCODER");
            }
        }
    }

    else if (!motor_direction && encoder_count <= target_ticks) {

        stopMotor();
        motor_running = false;

        encoder_count = 0;

        state = REST;
        state_time = millis();
    }
}

void logData() {

    if (!session_active) return;

    uint32_t now = micros();

    if (now - last_log_us < LOG_PERIOD_US)
        return;

    last_log_us = now;

    if (!client || !client.connected())
        return;

    uint32_t t_ms = millis() - session_start_ms;
    int adc_index = analogRead(32);
    int adc_thumb = analogRead(33);
    double vars[3] = {0};
    readMagsense(vars);


    int test_id = cycle_num;
    if (state == PRE || state == POST)
        test_id = 0;

    char msg[128];

    snprintf(
        msg,
        sizeof(msg),
        "DATA,%lu,%ld,%d,%d,%.3f,%.3f,%.3f,%d\n",
        t_ms,
        encoder_count,
        adc_index,
        adc_thumb,
        vars[0],
        vars[1],
        vars[2],
        test_id
    );

    client.write((uint8_t*)msg, strlen(msg));
}

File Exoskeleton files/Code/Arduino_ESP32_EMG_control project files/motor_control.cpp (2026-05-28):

#include <Arduino.h>
#include "motor_control.h"
#include "tcp_server.h"
#include "Magsense.h"
#include "config.h"

volatile long encoder_count = 0;

long target_ticks = 0;
bool motor_running = false;
bool motor_direction = true;
int max_enc = 3500; //2500// // 4500

uint32_t last_log_us = 0;
uint32_t session_start_ms = 0;

bool session_active = false;
int cycle_num = 0;

enum MotionState {
    POS_RELEASED,
    POS_CONTRACTING,
    POS_CONTRACTED,
    POS_RELEASING
};

MotionState motion_state = POS_RELEASED;


void IRAM_ATTR encoderISR() {
    if (motor_direction)
        encoder_count++;
    else
        encoder_count--;
}


void initMotor() {

    pinMode(AIN1_PIN, OUTPUT);
    pinMode(ENC_A_PIN, INPUT);
    pinMode(ENC_B_PIN, INPUT);

    attachInterrupt(digitalPinToInterrupt(ENC_A_PIN), encoderISR, CHANGE);

    ledcAttachChannel(AIN2_PIN, PWM_FREQ, PWM_BITS, PWM_CHANNEL_MOTOR);
    ledcWrite(AIN2_PIN, 0);
}


void stopMotor() {
    ledcWrite(AIN2_PIN, 0);
}


void moveTo(long target, bool dir) {

    motor_direction = dir;
    target_ticks = target;
    motor_running = true;

    digitalWrite(AIN1_PIN, dir ? HIGH : LOW);
    ledcWrite(AIN2_PIN, 255);
}


void protocolRoutine() {

    String cmd = getCommand();

    if (cmd == "startsession" && !session_active) {

        // Only allow a new session when fully released and idle
        if (!motor_running && motion_state == POS_RELEASED) {

            session_active = true;
            cycle_num = 0;
            session_start_ms = millis();
            last_log_us = 0;

            noInterrupts();
            encoder_count = 0;
            interrupts();

            client.println("SESSION STARTED");
        } else {
            client.println("IGNORED: STARTSESSION_NOT_RELEASED");
        }
    }

    else if (cmd == "contract" && session_active) {

        // Only allow contraction from the released position
        if (!motor_running && motion_state == POS_RELEASED) {

            cycle_num++;

            moveTo(max_enc, true);
            motion_state = POS_CONTRACTING;

            client.print("MOTION_STARTED,contract,");
            client.println(cycle_num);
        } else {
            client.println("IGNORED: CONTRACT");
        }
    }

    else if (cmd == "release" && session_active) {

        // Only allow release from the contracted position
        if (!motor_running && motion_state == POS_CONTRACTED) {

            moveTo(0, false);
            motion_state = POS_RELEASING;

            client.print("MOTION_STARTED,release,");
            client.println(cycle_num);
        } else {
            client.println("IGNORED: RELEASE");
        }
    }

    else if (cmd == "endsession" && session_active) {

        // Only allow session end when fully released and idle
        if (!motor_running && motion_state == POS_RELEASED) {

            session_active = false;
            client.println("SESSION DONE");
        } else {
            client.println("IGNORED: ENDSESSION_NOT_RELEASED");
        }
    }
}


void checkMotorStop() {

    if (!motor_running) return;

    long current_count;

    noInterrupts();
    current_count = encoder_count;
    interrupts();

    if (motion_state == POS_CONTRACTING) {

        double mag_vars[3] = {0};
        readMagsense(mag_vars);

        float x_gauss = mag_vars[0] * 8.0;
        bool mag_triggered = (x_gauss <= MAG_THRESHOLD);

        if (current_count >= target_ticks || mag_triggered) {

            stopMotor();
            motor_running = false;
            motion_state = POS_CONTRACTED;

            if (mag_triggered) {
                client.println("STOP_CAUSE: MAGNET");
            } else {
                client.println("STOP_CAUSE: ENCODER");
            }

            client.print("MOTION_DONE,contract,");
            client.println(cycle_num);
        }
    }

    else if (motion_state == POS_RELEASING) {

        if (current_count <= target_ticks) {

            stopMotor();
            motor_running = false;

            noInterrupts();
            encoder_count = 0;
            interrupts();

            motion_state = POS_RELEASED;

            client.print("MOTION_DONE,release,");
            client.println(cycle_num);
        }
    }
}


void logData() {

    if (!session_active) return;

    uint32_t now = micros();

    if (now - last_log_us < LOG_PERIOD_US)
        return;

    last_log_us = now;

    if (!client || !client.connected())
        return;

    uint32_t t_ms = millis() - session_start_ms;

    int adc_index = analogRead(32);
    int adc_thumb = analogRead(33);

    double vars[3] = {0};
    readMagsense(vars);

    long current_count;

    noInterrupts();
    current_count = encoder_count;
    interrupts();

    int test_id = cycle_num;

    char msg[128];

    snprintf(
        msg,
        sizeof(msg),
        "DATA,%lu,%ld,%d,%d,%.3f,%.3f,%.3f,%d\n",
        t_ms,
        current_count,
        adc_index,
        adc_thumb,
        vars[0],
        vars[1],
        vars[2],
        test_id
    );

    client.write((uint8_t*)msg, strlen(msg));
}

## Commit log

2026-05-28 added more files
    [Attachement plate.stl, Electronics enclosure and plate.stl, Enclosure lid.stl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]
2026-05-28 Create README.md for SoFiE exoskeleton
    Added detailed README for the SoFiE exoskeleton project, including an overview, file structure, hardware requirements, materials, and environment setup instructions.
2026-06-01 Full Repo Update
    [MVC_baseline_mvc.csv, MVC_baseline_mvc_Newest.csv, MVC_baseline_noise.csv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]
